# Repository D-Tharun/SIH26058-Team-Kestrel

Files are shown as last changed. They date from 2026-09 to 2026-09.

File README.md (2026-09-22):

# KESTREL — Adaptive Software-Defined Sonar Transmitter Payload for AUVs

**Smart India Hackathon 2026 — Problem Statement SIH26058**








| Team | Team ID | Institution |
|---|---|---|
| **KESTREL** | **127602** | SRM Institute of Science and Technology, Ramapuram |

> **Live Dashboard:** [aquachirp-sonar-transmitter.vercel.app](https://aquachirp-sonar-transmitter.vercel.app/)

---

## Hardware and Prototype Snapshot

**Measured on Rigol DS1054Z**

| Barker-13 | CW Signal | LFM Chirp |
| :---: | :---: | :---: |
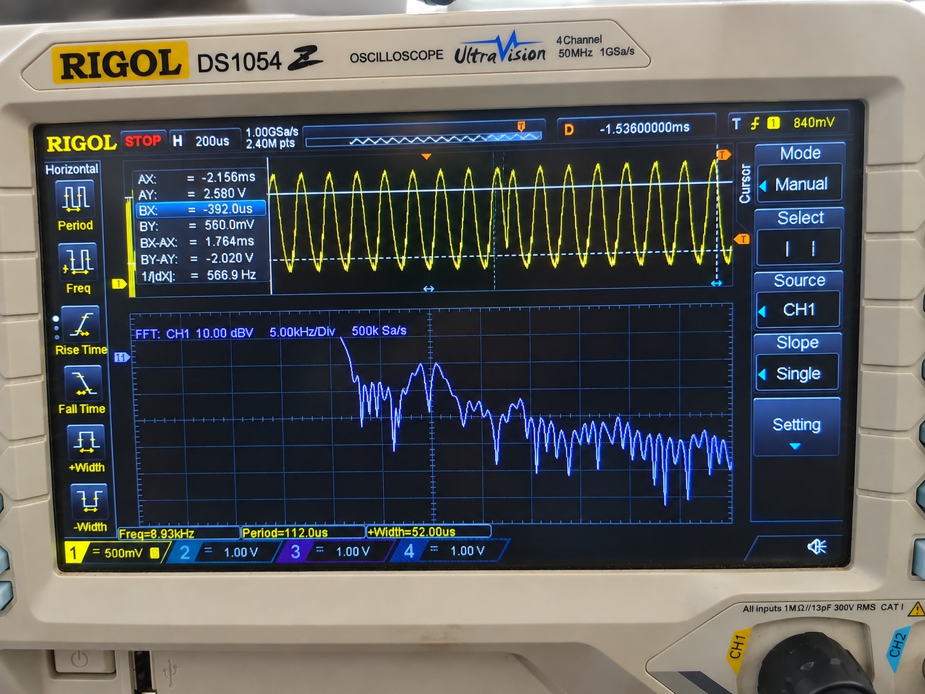
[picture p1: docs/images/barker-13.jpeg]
barker 13
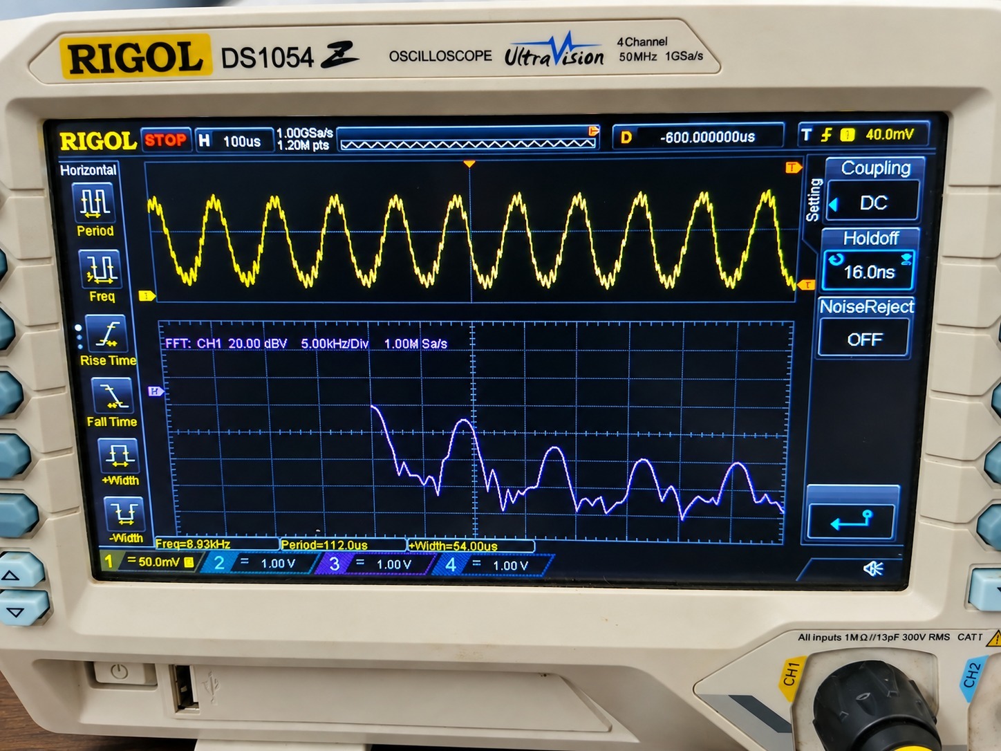
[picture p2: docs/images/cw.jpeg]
cw
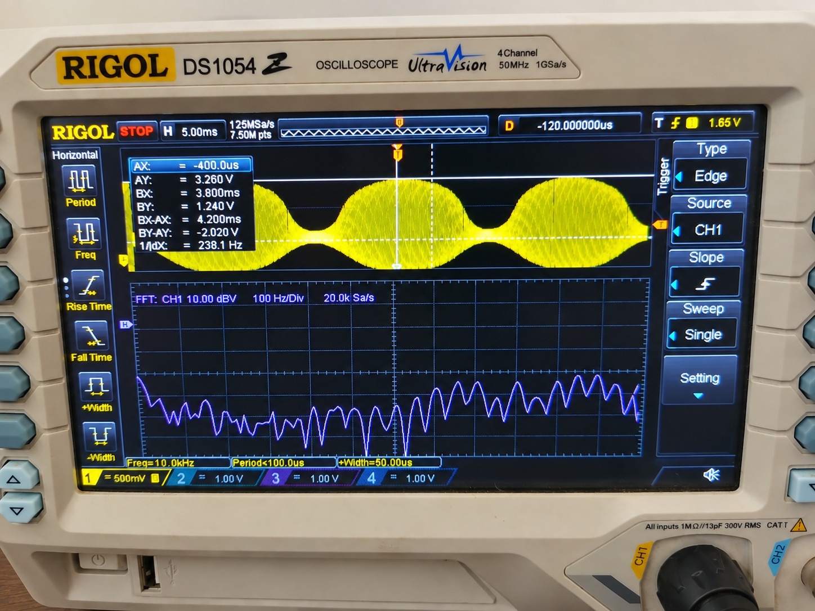
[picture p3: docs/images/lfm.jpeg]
lfm chirp
|  |  |  |

| Embedded Core | DAC | Physical Validation | Mechanical Integration |
|---|---|---|---|
| STM32F103RBT6 | MCP4921 12-bit | Rigol DS1054Z | AUV 3D CAD |

---

## Problem Statement

Conventional sonar transmitters are designed around fixed transmission parameters, making them inflexible when underwater environmental conditions change.

For an AUV operating in varying conditions, parameters such as depth, temperature, turbidity, salinity and the required balance between resolution and penetration can influence the choice of transmission strategy.

SIH26058 calls for a **software-defined, low-power and real-time adaptive sonar transmitter payload** capable of generating configurable waveforms and adapting its transmission parameters according to environmental conditions.

---

## Solution

KESTREL is a software-defined sonar transmitter payload built around an STM32 microcontroller and a configurable analog signal chain. The system continuously processes environmental inputs and selects an appropriate transmission strategy. The selected waveform is generated digitally, streamed through the DAC using hardware-timed data transfer, reconstructed through the analog signal chain, and validated using an oscilloscope.

**Core Pipeline: Sense — Adapt — Synthesize — Convert — Filter — Validate**

| PS Requirement | KESTREL Implementation |
|---|---|
| Software-defined transmitter | STM32-based firmware-controlled waveform generation |
| Real-time adaptation | Environmental inputs drive transmission-strategy selection |
| Multiple waveform types | CW, LFM Chirp, Geometric Sweep and Barker-13 phase coding |
| Low-power operation | Timer + DMA used for waveform sample streaming |
| Digital waveform synthesis | Firmware-generated waveform samples with LUT-based DDS |
| Analog transmission chain | MCP4921 DAC, CD4053B analog MUX, MCP6004 active filters |
| Real-time environmental inputs | Temperature, Turbidity, Salinity/TDS, Depth, Resolution-Penetration preference |
| Waveform validation | Rigol DS1054Z time-domain and FFT measurements |
| AUV payload integration | Compact 3D-designed streamlined payload enclosure |

---

## Repository Structure

```text
SIH26058-Team-Kestrel/
|
|-- firmware/                          STM32 Edge Firmware
|   +-- kestrel_waveform_engine.c      Adaptive DMA waveform engine (1556 lines)
|
|-- hardware/                          Physical Circuits and Interfaces
|   +-- Wiring Guide.md                Master pin-to-pin wiring reference
|
|-- mechanical/                        3D AUV Payload Concept
|   +-- cad/
|       |-- AUV_payload_streamlined.stl   230 mm x 100 mm hydrodynamic hull
|       |-- AUV_service_panel.stl         120 mm quick-access hatch
|       +-- AUV_hinge_pin.stl            3.4 mm diameter pivot dowel
|
|-- docs/                              Engineering Documentation
|   +-- Architecture.md                Complete system architecture flow
|
|-- src/                               Live Web DSP Telemetry Dashboard
|   |-- components/                     Oscilloscope, Waterfall, Radar, Decision views
|   |-- utils/                          Acoustic decision engine, signal generator
|   +-- App.tsx                         Main application with WebSerial integration
|
|-- README.md                          This file
|-- package.json                       Web dashboard dependencies
+-- vite.config.ts                     Build configuration
```

---

## System Architecture

```mermaid
graph TD
    subgraph Env["Environmental Inputs"]
        E1["Depth"]
        E2["Temperature"]
        E3["Turbidity"]
        E4["Salinity"]
        E5["Resolution / Penetration"]
    end
    
    subgraph MCU["STM32F103RBT6"]
        M1["Sensor Acquisition (ADC1/ADC2)"]
        M2["Adaptive Decision Engine"]
        M3["DDS Waveform Synthesis (LUT)"]
        M4["DMA Circular Buffer Streaming"]
    end

    Env --> MCU
    MCU -- "Timer + DMA" --> DAC["MCP4921 DAC<br>12-bit SPI"]
    MCU -- "Timer + DMA" --> TX["USART2 TX<br>115200 baud<br>JSON Telemetry"]
    
    DAC --> Analog["Analog Signal Chain<br>RC Filter<br>CD4053B MUX<br>MCP6004 Buffer"]
    TX --> Web["Web Dashboard<br>WebSerial API<br>React + Vite"]
    
    Analog --> Output["Analog Output"]
    Output --> DSO["Rigol DS1054Z<br>Time + FFT"]
```

---

## Signal Flow

```mermaid
flowchart TD
    A["Environmental Inputs"] --> B["STM32 ADC Data Acquisition"]
    B --> C["Adaptive Transmission Logic"]
    C --> D["Waveform Synthesis (Phase Accumulator + LUT)"]
    D --> E["Timer + DMA Sample Streaming"]
    E --> F["MCP4921 12-bit DAC"]
    F --> G["Analog Reconstruction Filter"]
    G --> H["CD4053B Filter Selection (PB5 controlled)"]
    H --> I["MCP6004 Buffer / Conditioning"]
    I --> J["Analog Output"]
    J --> K["Oscilloscope Validation (Time Domain + FFT)"]
```

---

## Adaptive Modulation Rules

The decision engine selects waveform modulation based on environmental state:

| Condition | Selected Modulation | Rationale |
|---|---|---|
| Depth > 80 m | Barker-13 (BPSK) | 11.1 dB pulse compression gain for deep-water clutter rejection |
| Turbidity < 30 NTU and Depth < 30 m | CW (Continuous Wave) | Narrowband Doppler estimation in clean shallow water |
| Turbidity > 60 NTU | LFM Chirp | Pulse compression through suspended particulate scattering |
| Turbidity 30-60 NTU | Geometric Sweep | Doppler-tolerant wideband energy for moderate scattering |
| Default fallback | Barker-13 | Standard phase coding for reliable SNR compression |

Window function selection follows SNR estimation:

| Condition | Window | Sidelobe Rejection |
|---|---|---|
| CW mode or SNR > 15 dB | Hamming | -43 dB |
| SNR 7-15 dB | Hann | -31 dB |
| SNR < 7 dB | Blackman | -58 dB |

---

## STM32 Pin Map

| Pin | Peripheral | Connection | Function |
|---|---|---|---|
| PA0 / A0 | ADC1_IN0 | Potentiometer 1 | Resolution / Penetration preference (0.0 - 1.0) |
| PA1 / A1 | ADC1_IN1 | Potentiometer 2 | Turbidity (SEN0189 / 10k-22k divider) |
| PA4 / A2 | ADC1_IN4 | Potentiometer 3 | Temperature (5 - 35 deg C) |
| PB0 / A3 | ADC1_IN8 | Potentiometer 4 | Depth / Water Level (0 - 200 m) |
| PC0 / A5 | ADC1_IN10 | Potentiometer 5 | Salinity / TDS (0 - 40 PSU) |
| PA6 / D12 | TIM3_CH1 | PWM Output | Waveform DMA output at 100 kSPS (ARR = 639) |
| PC1 / A4 | ADC2_IN11 | Self-Monitor | Final waveform loopback (64-sample feedback) |
| PB5 / D4 | GPIO Output | CD4053B Select | Dynamic filter capacitor selection |
| PA2 / D1 | USART2 TX | ST-LINK VCP | JSON telemetry at 115200 baud |
| PA3 / D0 | USART2 RX | ST-LINK VCP | Serial receive |
| PC13 | GPIO Output | User LED | DMA loop heartbeat indicator |

---

## Analog Signal Chain

```mermaid
flowchart TD
    PWM["PA6 / D12 (TIM3_CH1 PWM)"] --> R1["1kΩ Resistor"]
    R1 --> FILT1{"FILT1 Node"}
    
    FILT1 --> MUX["CD4053B MUX (Pin 14)"]
    MUX -- "PB5=0" --> C1["100 nF Capacitor to GND"]
    MUX -- "PB5=1" --> C2["10 nF Capacitor to GND"]
    
    FILT1 --> BUFA["MCP6004 Ch.A (Voltage Follower)"]
    BUFA --> R2["1kΩ Resistor"]
    R2 --> FILT2{"FILT2 Node"}
    
    FILT2 --> C3["10 nF Capacitor to GND"]
    FILT2 --> BUFB["MCP6004 Ch.B (Voltage Follower)"]
    
    BUFB --> WAVE{"FINAL WAVE Node"}
    WAVE --> DSO["DSO / Transducer"]
    WAVE --> R3["10kΩ Resistor"]
    
    R3 --> WAVEMON{"WAVE_MON Node"}
    WAVEMON --> ADC["PC1 / A4 (ADC2 Loopback)"]
    WAVEMON --> C4["1 nF Capacitor to GND"]
```

---

## Experimental Validation

### Oscilloscope Measurements

All waveforms were measured at the FINAL WAVE output node using a Rigol DS1054Z digital storage oscilloscope. (See the Hardware and Prototype Snapshot section at the top of this document for the waveform captures).

### Power Measurement

The transmitter signal chain was measured at 3.3 V using a digital multimeter connected in series with the supply.

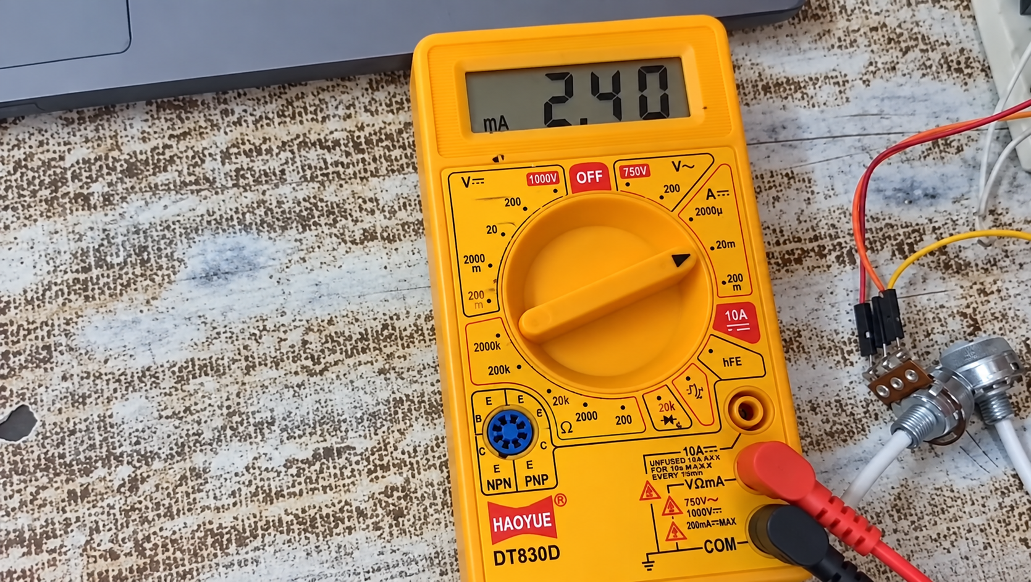
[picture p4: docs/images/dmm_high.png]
DMM Measurement

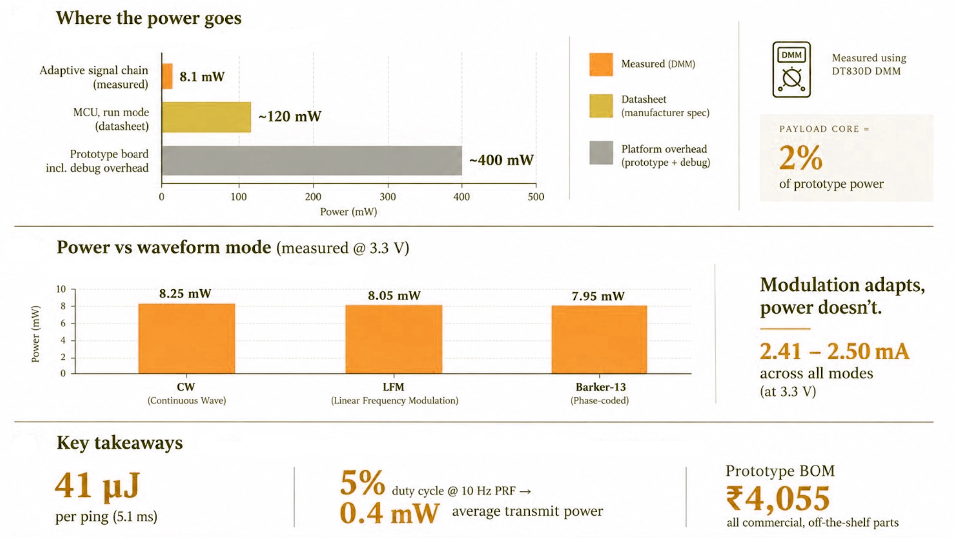
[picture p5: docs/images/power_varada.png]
Power Validation


| Waveform Mode | Measured Power | Equivalent Current |
|---|---:|---:|
| CW | 8.25 mW | 2.50 mA |
| LFM Chirp | 8.05 mW | 2.44 mA |
| Barker-13 | 7.95 mW | 2.41 mA |

Across all tested waveform modes, the measured signal-chain power remained within **7.95 - 8.25 mW**, corresponding to approximately **2.41 - 2.50 mA at 3.3 V**.

> **Measurement scope:** These values represent the 3.3 V transmitter signal-chain section only and do not represent the total power consumption of the complete development-board system.

---

## AUV Mechanical Integration

A 3D CAD enclosure was developed to explore the mechanical integration of the transmitter electronics into an AUV payload module.

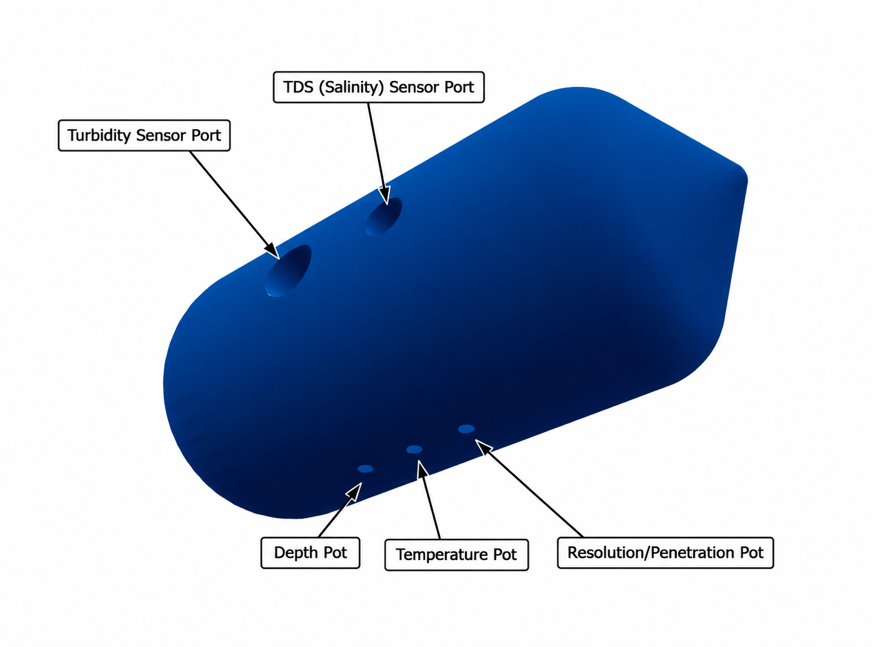
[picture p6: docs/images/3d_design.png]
3D CAD Concept


| Component | Dimensions | Description |
|---|---|---|
| Streamlined Hull | 230 mm x 100 mm diameter | Hydrodynamic cylindrical body of revolution |
| Service Panel | 120 mm x 80.6 mm arc | Quick-access hatch with conformal profile |
| Hinge Pin | 90.8 mm x 3.4 mm diameter | Cylindrical pivot dowel for panel articulation |

### Design Features

- Compact cylindrical form factor compatible with standard AUV payload bays
- Internal dry electronics cavity (62 - 92 mm inner diameter)
- Removable service panel with hinge mechanism for field access
- Rear cable pass-through provision
- Sensor and PCB mounting provisions
- Parabolic forebody profile for minimal hydrodynamic drag

> The current CAD represents a **prototype mechanical integration concept** and is not claimed as a pressure-rated or waterproof housing.

STL files are available in [`mechanical/cad/`](mechanical/cad/).

---

## Acoustic Physics

### Mackenzie Sound Speed Equation (1981)

```
c(T, S, D) = 1448.96 + 4.591T - 0.05304T^2 + 2.374e-4 T^3
            + 1.340(S - 35) + 1.630e-2 D + 1.675e-7 D^2
            - 1.025e-2 T(S - 35) - 7.139e-13 T D^3
```

Where T is temperature (deg C), S is salinity (PSU) and D is depth (m).

### Francois-Garrison Absorption Model

```
alpha(f) = A1*P1*(f1*f^2)/(f1^2 + f^2) + A2*P2*(f2*f^2)/(f2^2 + f^2) + A3*P3*f^2   [dB/km]
```

Accounts for Boric Acid relaxation, Magnesium Sulfate relaxation, and pure water viscous attenuation.

### Range Resolution and Pulse Compression

```
Delta_R = c / (2 * B)
G_p = 10 * log10(B * tau)   [dB]
```

---

## Serial Telemetry Protocol

The STM32 transmits line-delimited JSON frames at 10 Hz over USB Virtual COM Port (115200 baud):

```json
{
  "depth": 65.0,
  "turbidity": 0.42,
  "temperature": 21.0,
  "res_pen": 0.50,
  "salinity": 34.5,
  "sound_speed": 1522.4,
  "absorption": 1.20,
  "snr": 18.5,
  "center_freq": 2400.0,
  "bandwidth": 1522.4,
  "duration": 16.3,
  "amplitude": 0.61,
  "waveform_type": 1,
  "window_type": 0,
  "adc_samples": [320, 345, 390, 420, 380, 310, 260, 240, 280, 320]
}
```

---

## Getting Started

### Prerequisites

- [Node.js](https://nodejs.org/) v18 or higher
- Google Chrome, Microsoft Edge or any Chromium browser supporting the WebSerial API

### Clone the Repository

```bash
git clone https://github.com/D-Tharun/SIH26058-Team-Kestrel.git
cd SIH26058-Team-Kestrel
```

### Install Dependencies

```bash
npm install
```

### Start Development Server

```bash
npm run dev
```

Open [http://localhost:3000](http://localhost:3000) in your browser.

### Build for Production

```bash
npm run build
```

---

## Deployment

This repository is configured for zero-configuration deployment on Vercel:

1. Push this repository to GitHub.
2. Link the repository to [Vercel](https://vercel.com).
3. The platform will automatically build and deploy on every push.
4. Access the live HTTPS dashboard and click **Connect USB** to link your physical STM32 hardware.

**Live deployment:** [aquachirp-sonar-transmitter.vercel.app](https://aquachirp-sonar-transmitter.vercel.app/)

---

## Current Prototype Scope

### Demonstrated

- STM32 Nucleo F103RB embedded controller
- Controlled environmental-input emulation via potentiometers
- Adaptive waveform selection based on environmental state
- CW, LFM Chirp, Geometric Sweep and Barker-13 waveform generation
- MCP4921 DAC with Timer + DMA streaming
- Analog signal conditioning (MCP6004 + CD4053B + RC filtering)
- Physical DSO verification (time-domain and FFT)
- Signal-chain power measurement (7.95 - 8.25 mW)
- Mechanical CAD concept for AUV payload integration
- Real-time web telemetry dashboard with WebSerial API

### Future Development

- Real environmental sensors (DS18B20, SEN0189, TDS probe)
- Dedicated PCB layout
- Higher-frequency acoustic implementation
- Power amplifier stage
- Transducer integration and impedance matching
- Pressure-rated waterproof payload enclosure
- End-to-end underwater acoustic testing

---

## License

This project is open-source and available under the [MIT License](LICENSE).

---

**Team KESTREL | SIH26058 | SRM Institute of Science and Technology, Ramapuram**

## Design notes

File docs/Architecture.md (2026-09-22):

# KESTREL — SIH 26058
## Complete Project Architecture Flow

**Project:** Development of a Low-Power, Real-Time Adaptive Software-Defined Sonar Transmitter Payload for Autonomous Underwater Vehicles (AUVs)

---

## 1. Complete Architecture

```text
┌─────────────────────────────────────────────────────────────────────┐
│              CONTROLLED ENVIRONMENTAL INPUTS                       │
│                                                                     │
│  Depth │ Temperature │ Turbidity │ Salinity │ Resolution/Input     │
│                                                                     │
│  Current prototype: potentiometers used as input emulators         │
└───────────────────────────────┬─────────────────────────────────────┘
                                │
                                ▼
┌─────────────────────────────────────────────────────────────────────┐
│                     DATA ACQUISITION                                │
│                                                                     │
│                 STM32 Nucleo F103RB + ADC                           │
│                                                                     │
│       Analog input voltages → Digital environmental values          │
└───────────────────────────────┬─────────────────────────────────────┘
                                │
                                ▼
┌─────────────────────────────────────────────────────────────────────┐
│                 ENVIRONMENT ANALYSIS / ESTIMATION                  │
│                                                                     │
│  Interpret the current environmental state and determine the       │
│  required acoustic operating condition.                            │
└───────────────────────────────┬─────────────────────────────────────┘
                                │
                                ▼
┌─────────────────────────────────────────────────────────────────────┐
│                     ADAPTIVE DECISION                              │
│                                                                     │
│  Environmental state → waveform selection → parameter selection    │
│                                                                     │
│  Parameters:                                                        │
│  • Centre / carrier frequency                                       │
│  • Bandwidth                                                        │
│  • Pulse duration                                                   │
│  • Amplitude / signal level                                         │
│  • Modulation / coding                                              │
│  • Digital window                                                   │
│  • PRF / timing parameters                                          │
└───────────────────────────────┬─────────────────────────────────────┘
                                │
                 ┌──────────────┴──────────────┐
                 │                             │
                 ▼                             ▼
┌──────────────────────────┐       ┌──────────────────────────────────┐
│     PC DASHBOARD         │       │       WAVEFORM GENERATOR         │
│                          │       │                                  │
│ • Environmental values  │       │ • LUT / mathematical synthesis   │
│ • Selected waveform      │       │ • Phase accumulator               │
│ • Commanded parameters   │       │ • Waveform-specific generation   │
│ • Decision information   │       │ • Digital windowing              │
└──────────────────────────┘       └────────────────┬─────────────────┘
                                                    │
                                                    ▼
                                      ┌──────────────────────────────┐
                                      │       TIMER + DMA            │
                                      │                              │
                                      │ Timer → sample timing        │
                                      │ DMA   → sample transfer      │
                                      │                              │
                                      │ Reduces continuous CPU      │
                                      │ involvement during streaming │
                                      └───────────────┬──────────────┘
                                                      │
                                                      ▼
                                      ┌──────────────────────────────┐
                                      │        MCP4921 DAC           │
                                      │                              │
                                      │ Digital samples → analog     │
                                      │ voltage waveform              │
                                      └───────────────┬──────────────┘
                                                      │
                                                      ▼
                                      ┌──────────────────────────────┐
                                      │      ANALOG CONDITIONING     │
                                      │                              │
                                      │ • MCP6004 buffer/amplifier   │
                                      │ • Analog low-pass filter     │
                                      │ • Signal conditioning        │
                                      └───────────────┬──────────────┘
                                                      │
                                                      ▼
                                      ┌──────────────────────────────┐
                                      │       PHYSICAL OUTPUT        │
                                      │        WAVEFORM NODE         │
                                      └───────────────┬──────────────┘
                                                      │
                                                      ▼
                                      ┌──────────────────────────────┐
                                      │          VERIFY              │
                                      │                              │
                                      │ DSO time-domain measurement  │
                                      │ DSO FFT / spectrum analysis  │
                                      └───────────────┬──────────────┘
                                                      │
                                                      ▼
                                      ┌──────────────────────────────┐
                                      │     VALIDATION / FEEDBACK     │
                                      │                              │
                                      │ Compare commanded and        │
                                      │ measured waveform behaviour  │
                                      └───────────────┬──────────────┘
                                                      │
                                                      └──────► Next
                                                              input state
```

---

## 2. High-Level Architecture

```text
        ┌─────────┐
        │  SENSE  │
        └────┬────┘
             ↓
        ┌─────────┐
        │ ACQUIRE │
        └────┬────┘
             ↓
        ┌─────────┐
        │ ANALYSE │
        └────┬────┘
             ↓
        ┌─────────┐
        │  ADAPT  │
        └────┬────┘
             ↓
        ┌─────────┐
        │GENERATE │
        └────┬────┘
             ↓
        ┌─────────┐
        │   DAC   │
        └────┬────┘
             ↓
        ┌──────────────┐
        │   ANALOG     │
        │ CONDITIONING │
        └──────┬───────┘
               ↓
        ┌─────────┐
        │ VERIFY  │
        └────┬────┘
             ↓
          DSO + FFT
```

---

## 3. Environmental Input Layer

The current prototype uses five controlled potentiometer inputs as environmental-condition emulators.

```text
Depth
Temperature
Turbidity
Salinity
Resolution / related input
       │
       ▼
Analog voltage
       │
       ▼
STM32 ADC
       │
       ▼
Digital input values
```

These potentiometers should be described as **controlled environmental inputs/emulators**, not as functioning underwater sensors.

---

## 4. Embedded Controller

### STM32 Nucleo F103RB

The STM32 performs the central embedded processing:

1. Reads the ADC inputs.
2. Interprets the current environmental state.
3. Selects the adaptive waveform mode.
4. Determines waveform parameters.
5. Generates waveform samples.
6. Controls real-time sample streaming.
7. Interfaces with the external DAC.
8. Provides system information to the monitoring/dashboard layer.

---

## 5. Adaptive Decision Layer

The core project relationship is:

```text
Changing environmental inputs
             ↓
     Environment analysis
             ↓
       Adaptive decision
             ↓
    Waveform + parameters
```

The waveform modes demonstrated in the prototype are:

```text
                 ┌───────────┐
                 │    CW     │
                 └───────────┘

                 ┌───────────┐
                 │    LFM    │
                 └───────────┘

                 ┌───────────┐
                 │ Geometric │
                 │   Sweep   │
                 └───────────┘

                 ┌───────────┐
                 │ Barker-13 │
                 └───────────┘
```

---

## 6. Waveform Generation

The waveform engine uses mathematical synthesis on the STM32.

### General generation chain

```text
Waveform parameters
       ↓
Mathematical synthesis
       ↓
LUT / phase control
       ↓
Digital waveform samples
       ↓
Waveform buffer
```

### CW

```text
Constant phase increment
        ↓
Constant instantaneous frequency
        ↓
CW waveform
```

### LFM

```text
Changing phase increment
        ↓
Changing instantaneous frequency
        ↓
LFM chirp
```

### Geometric Sweep

```text
Time-varying frequency
according to implemented sweep relationship
        ↓
Geometric sweep waveform
```

### Barker-13

```text
Carrier
  +
Barker phase/sign sequence
  ↓
Phase-coded waveform
```

---

## 7. Digital Windowing

Where configured:

```text
Generated waveform
        ↓
Digital window
        ↓
Windowed waveform samples
        ↓
DAC streaming
```

The demonstrated configurations include windowing such as Hamming and Blackman.

---

## 8. Timer + DMA Architecture

The timer and DMA are important to the real-time hardware architecture.

```text
                WAVEFORM BUFFER
                       │
                       ▼
                     DMA
                       │
                       ▼
                  MCP4921 DAC
                       │
                       ▼
                Analog waveform

Hardware Timer
      │
      └── controls sample-update timing
```

### Hardware Timer

Controls when waveform samples are updated.

### DMA

Moves waveform samples toward the DAC without requiring the CPU to manually handle every individual sample transfer.

### CPU

Handles control logic, parameter processing and waveform preparation while hardware peripherals handle the repetitive streaming operation.

---

## 9. DAC and Analog Signal Chain

```text
STM32 waveform data
        ↓
      DMA
        ↓
   MCP4921 DAC
        ↓
   Analog voltage
        ↓
 MCP6004 / buffer
        ↓
 Analog low-pass filter
        ↓
 Conditioned analog waveform
        ↓
 Physical output node
```

---

## 10. Physical Verification

The output is physically verified using a Digital Storage Oscilloscope.

### Time-domain verification

```text
Physical analog output
        ↓
        DSO
        ↓
• Waveform shape
• Period
• Local frequency
• Pulse behaviour
```

### Frequency-domain verification

```text
Physical analog output
        ↓
      DSO FFT
        ↓
• Dominant frequency
• Spectrum
• Frequency-domain behaviour
```

The terminology should distinguish between:

- **Commanded value** — requested by the controller.
- **Measured value** — observed on the DSO.

---

## 11. PC Dashboard

The dashboard is a monitoring/presentation layer.

```text
                 STM32
                   │
          ┌────────┴────────┐
          │                 │
          ▼                 ▼
   PC Dashboard       Waveform Engine
          │                 │
          │                 ▼
          │              DMA/DAC
          │                 │
          ▼                 ▼
 Selected waveform      Physical output
 Parameters                  │
 Decision state               ▼
                          DSO / FFT
```

The dashboard displays system state and commanded parameters; the physical analog waveform is generated by the embedded hardware and DAC/analog chain.

---

## 12. Complete Signal Path

```text
Environmental inputs
        ↓
STM32 ADC
        ↓
Environment analysis
        ↓
Adaptive decision
        ↓
Waveform selection
        ↓
Parameter generation
        ↓
Waveform synthesis
        ↓
Digital windowing
        ↓
Waveform buffer
        ↓
Hardware Timer + DMA
        ↓
MCP4921 DAC
        ↓
MCP6004 / analog conditioning
        ↓
Analog low-pass filter
        ↓
Physical waveform output
        ↓
DSO
   ┌────┴────┐
   ↓         ↓
Time       FFT
domain     spectrum
```

---

## 13. Closed Adaptive Loop

```text
        ┌───────────────────────────┐
        │ ENVIRONMENTAL INPUT       │
        │ Controlled / emulated     │
        └─────────────┬─────────────┘
                      ↓
        ┌───────────────────────────┐
        │ ACQUIRE                    │
        │ STM32 ADC                  │
        └─────────────┬─────────────┘
                      ↓
        ┌───────────────────────────┐
        │ ANALYSE                    │
        │ Environmental state        │
        └─────────────┬─────────────┘
                      ↓
        ┌───────────────────────────┐
        │ ADAPT                      │
        │ Waveform + parameters      │
        └─────────────┬─────────────┘
                      ↓
        ┌───────────────────────────┐
        │ GENERATE                   │
        │ Mathematical synthesis     │
        └─────────────┬─────────────┘
                      ↓
        ┌───────────────────────────┐
        │ DAC + ANALOG CONDITIONING │
        └─────────────┬─────────────┘
                      ↓
        ┌───────────────────────────┐
        │ PHYSICAL OUTPUT            │
        └─────────────┬─────────────┘
                      ↓
        ┌───────────────────────────┐
        │ VERIFY                     │
        │ DSO + FFT                  │
        └─────────────┬─────────────┘
                      │
                      └──────────────► Next environmental state
```

---

## 14. Power Architecture

The demonstrated power measurement applies to the **signal-generation electronics**.

```text
3.3 V supply
    ↓
Signal-generation electronics
    ↓
Measured current ≈ 2.4 mA
    ↓
Power ≈ 8 mW
```

This measurement does **not** represent:

- Total AUV payload power.
- Acoustic transmit power.
- Power consumption of a completed power amplifier.
- Transducer power.

The current prototype does not include the final power-amplifier and transducer stage.

---

## 15. Mechanical Payload Concept

The CAD concept provides a possible mechanical package for the electronics.

```text
        Streamlined cylindrical payload
                    │
        ┌───────────┴───────────┐
        │                       │
        ▼                       ▼
 Sensor openings        Side access ports
        │                       │
        │                Potentiometer access
        │
        └───────────┬───────────┘
                    ↓
             Electronics/
             service region
```

The current CAD is a concept design and is not a final pressure-rated or waterproof housing.

---

## 16. Current Prototype Scope

### Demonstrated

- STM32 Nucleo F103RB
- Controlled environmental-input emulation
- Adaptive waveform selection
- CW
- LFM
- Geometric sweep
- Barker-13 implementation
- MCP4921 DAC
- Timer/DMA streaming architecture
- Analog conditioning
- Physical DSO verification
- FFT/spectrum observation
- Signal-generation power measurement
- Mechanical CAD concept

### Future Development

- Real environmental sensors
- Dedicated PCB
- Higher-frequency implementation
- Power amplifier
- Transducer integration
- Final waterproof / pressure-rated payload enclosure
- End-to-end underwater acoustic testing

---

## 17. Final One-Line Architecture

> **ENVIRONMENT INPUT → ADC → ANALYSE → ADAPT → WAVEFORM GENERATION → TIMER + DMA → MCP4921 DAC → ANALOG CONDITIONING → PHYSICAL OUTPUT → DSO / FFT VERIFY**

---

## 18. Five-Word Project Story

> **SENSE → ANALYSE → ADAPT → GENERATE → VERIFY**

This is the simplest high-level representation of the KESTREL adaptive sonar transmitter architecture.

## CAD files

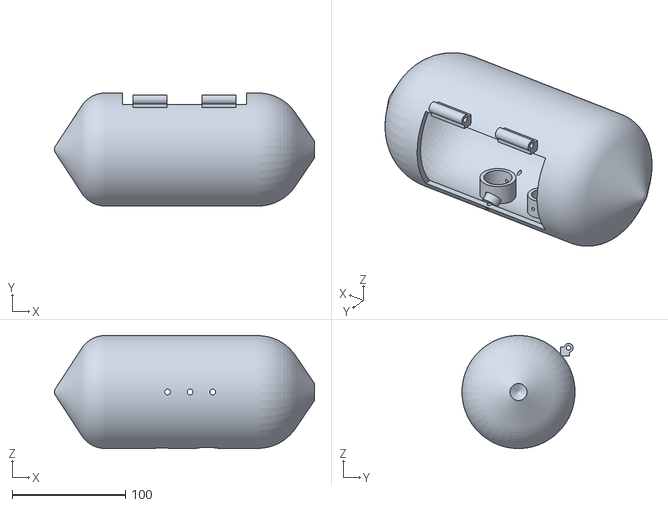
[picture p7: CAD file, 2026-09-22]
mechanical/cad/AUV_payload_streamlined.stl
230.0 x 100.0 x 100.0

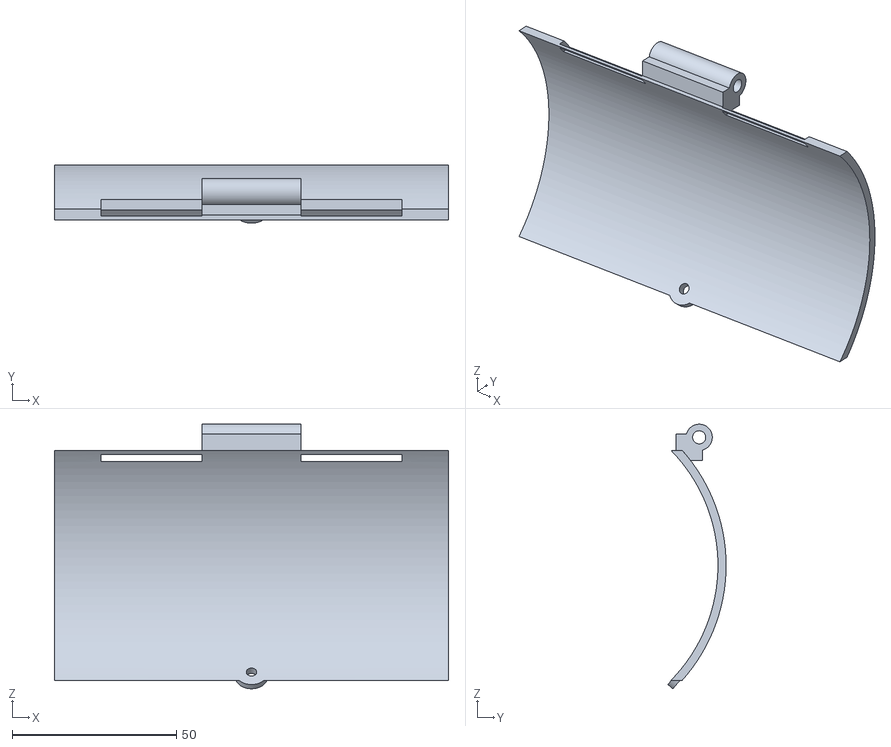
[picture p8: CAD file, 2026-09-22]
mechanical/cad/AUV_service_panel.stl
120.0 x 17.8 x 80.6

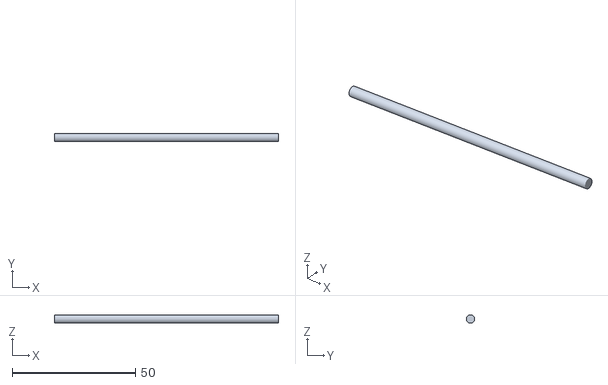
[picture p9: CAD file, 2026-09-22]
mechanical/cad/AUV_hinge_pin.stl
90.8 x 3.40 x 3.40

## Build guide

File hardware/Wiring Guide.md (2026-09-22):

## SIH 26058 — Adaptive Software-Defined Sonar Transmitter Payload

This guide documents the **5-pot prototype input configuration** used for environmental-input emulation.

The five 10 kΩ potentiometers represent:

1. Resolution / Penetration preference
2. Turbidity
3. Temperature
4. Depth
5. Salinity

All five potentiometers are wired as voltage dividers between **3.3 V and GND**. The **wiper** of each potentiometer goes to one STM32 ADC input.

---

## 1. Five-Pot Wiring Summary

| Potentiometer | Parameter | Value | One outer pin | Wiper | Other outer pin |
|---|---|---:|---|---|---|
| POT1 | RES-PEN | 10 kΩ | 3.3 V | PA0 / A0 | GND |
| POT2 | TURBIDITY | 10 kΩ | 3.3 V | PA1 / A1 | GND |
| POT3 | TEMP | 10 kΩ | 3.3 V | PA4 / A2 | GND |
| POT4 | DEPTH | 10 kΩ | 3.3 V | PB0 / A3 | GND |
| POT5 | SALINITY | 10 kΩ | 3.3 V | PC0 / A5 | GND |

> **Important:** The two outer terminals of every potentiometer form the 3.3 V–GND voltage divider. The center terminal is the ADC wiper.

---

## 2. Standard Potentiometer Connection

Each 10 kΩ potentiometer is wired in the same basic way:

```text
                 3.3 V
                   |
             +-----+-----+
             |   10 kΩ  |
             |    POT   |
             +-----+-----+
                   |
                  GND

                 WIPER
                   |
                   +-------- STM32 ADC INPUT
```

The wiper voltage varies approximately from **0 V to 3.3 V** as the knob is rotated.

---

## 3. POT1 — Resolution / Penetration

**Purpose:** Emulates the resolution-versus-penetration preference.

```text
POT1 — 10 kΩ

Outer pin 1  -> 3.3 V
Wiper        -> PA0 / A0
Outer pin 2  -> GND
```

**Label:** `RES-PEN`

---

## 4. POT2 — Turbidity

**Purpose:** Emulates the water turbidity/environmental condition.

```text
POT2 — 10 kΩ

Outer pin 1  -> 3.3 V
Wiper        -> PA1 / A1
Outer pin 2  -> GND
```

**Label:** `TURBIDITY`

---

## 5. POT3 — Temperature

**Purpose:** Emulates the temperature input during 5-pot prototype mode.

```text
POT3 — 10 kΩ

Outer pin 1  -> 3.3 V
Wiper        -> PA4 / A2
Outer pin 2  -> GND
```

**Label:** `TEMP`

---

## 6. POT4 — Depth

**Purpose:** Emulates operating depth.

```text
POT4 — 10 kΩ

Outer pin 1  -> 3.3 V
Wiper        -> PB0 / A3
Outer pin 2  -> GND
```

**Label:** `DEPTH`

---

## 7. POT5 — Salinity

**Purpose:** Emulates salinity/TDS during prototype mode.

```text
POT5 — 10 kΩ

Outer pin 1  -> 3.3 V
Wiper        -> PC0 / A5
Outer pin 2  -> GND
```

**Label:** `SALINITY`

---

## 8. Complete Five-Pot Wiring

```text
                         STM32 NUCLEO
                    +------------------+
                    |                  |
3.3 V --------------+------------------+-------------------+
                    |                  |                   |
GND ----------------+------------------+---------------+   |
                    |                  |               |   |
PA0 / A0 -----------+------------------+-----------+   |   |
PA1 / A1 -----------+------------------+---------+ |   |   |
PA4 / A2 -----------+------------------+-------+ | |   |   |
PB0 / A3 -----------+------------------+-----+ | | |   |   |
PC0 / A5 -----------+------------------+---+ | | | |   |   |
                    +------------------+   | | | | |   |   |
                                           | | | | |   |   |
             POT1 RES-PEN                  | | | | |   |   |
        3.3 V ----+                        | | | | |   |   |
                  | 10 kΩ                   | | | | |   |   |
                  +--- WIPER --------------+ | | | |   |   |
                  |      -> PA0 / A0         | | | |   |   |
        GND ------+                          | | | |   |   |
                                             | | | |   |   |
             POT2 TURBIDITY                  | | | |   |   |
        3.3 V ----+                          | | | |   |   |
                  | 10 kΩ                    | | | |   |   |
                  +--- WIPER ----------------+ | | |   |   |
                  |      -> PA1 / A1          | | |   |   |
        GND ------+                            | | |   |   |
                                               | | |   |   |
             POT3 TEMP                         | | |   |   |
        3.3 V ----+                            | | |   |   |
                  | 10 kΩ                      | | |   |   |
                  +--- WIPER ------------------+ | |   |   |
                  |      -> PA4 / A2            | | |   |   |
        GND ------+                              | |   |   |
                                                 | |   |   |
             POT4 DEPTH                          | |   |   |
        3.3 V ----+                              | |   |   |
                  | 10 kΩ                        | |   |   |
                  +--- WIPER --------------------+ |   |   |
                  |      -> PB0 / A3              | |   |   |
        GND ------+                                |   |   |
                                                   |   |   |
             POT5 SALINITY                         |   |   |
        3.3 V ----+                                |   |   |
                  | 10 kΩ                          |   |   |
                  +--- WIPER ----------------------+   |   |
                  |      -> PC0 / A5                   |   |
        GND ------+                                    |
```

For the physical prototype, use common **3.3 V** and **GND** rails and route each wiper separately to its assigned ADC pin.

---

## 9. STM32 ADC Mapping

| Parameter | STM32 Pin | Prototype Input |
|---|---|---|
| Resolution / Penetration | PA0 / A0 | POT1 |
| Turbidity | PA1 / A1 | POT2 |
| Temperature | PA4 / A2 | POT3 |
| Depth | PB0 / A3 | POT4 |
| Salinity | PC0 / A5 | POT5 |

Other relevant STM32 connections:

| STM32 pin | Function |
|---|---|
| PA6 | Current prototype waveform input / PWM path |
| PB5 | CD4053 A control |
| PC1 | FINAL WAVE self-monitor |
| 3V3 | Potentiometer supply |
| GND | Common ground |

**No 5 V rail is used for the five-pot prototype inputs.**

---

## 10. Electrical Principle

```text
POT POSITION
     |
     v
ANALOG VOLTAGE (0–3.3 V)
     |
     v
STM32 ADC
     |
     v
DIGITAL VALUE
     |
     v
ENVIRONMENTAL PARAMETER
     |
     v
ADAPTIVE TRANSMITTER DECISION
```

Each potentiometer acts as a variable voltage divider:

```text
3.3 V
  |
 10 kΩ POT
  |
 WIPER ---------> STM32 ADC
  |
 GND
```

---

## 11. MCP4921 DAC Wiring

The MCP4921 is the external 12-bit DAC used in the DAC-based waveform-generation path.

```text
STM32 NUCLEO              MCP4921 DAC
+-----------+             +-----------+
| PA5       | ----------> | SCK       |
| PA7       | ----------> | SDI/MOSI  |
| PB6       | ----------> | CS        |
| 3.3 V     | ----------> | VDD       |
| GND       | ----------> | VSS       |
+-----------+             |           |
                          | VOUT -----> R1 (1 kΩ)
                          +-----------+
                                      |
                                      v
                                    FILT1
                                      |
                                      v
                                    CD4053B
```

### MCP4921 Pin Connections

| MCP4921 pin/function | Connection |
|---|---|
| VDD | 3.3 V |
| VSS | GND |
| SCK | STM32 PA5 / SPI clock |
| SDI | STM32 PA7 / SPI MOSI |
| CS | STM32 PB6 / chip select |
| VOUT | R1 (1 kΩ) → FILT1 → CD4053B signal path |

Use a common ground between the STM32 and MCP4921.

The DAC signal path is:

```text
STM32 SPI
   |
   v
MCP4921 (12-bit DAC)
   |
   v
VOUT
   |
   v
R1 = 1 kΩ
   |
   v
FILT1
   |
   v
CD4053B
   |
   v
MCP6004 buffer
   |
   v
FINAL WAVE
```

This is the external-DAC waveform-generation configuration and is separate from the five-pot environmental-input wiring.

---
---

## 12. Final Five-Pot Pin Map

```text
POT1 RES-PEN    : 3.3 V -> 10 kΩ POT -> WIPER -> PA0/A0 -> GND
POT2 TURBIDITY  : 3.3 V -> 10 kΩ POT -> WIPER -> PA1/A1 -> GND
POT3 TEMP       : 3.3 V -> 10 kΩ POT -> WIPER -> PA4/A2 -> GND
POT4 DEPTH      : 3.3 V -> 10 kΩ POT -> WIPER -> PB0/A3 -> GND
POT5 SALINITY   : 3.3 V -> 10 kΩ POT -> WIPER -> PC0/A5 -> GND
```

**This is the complete 5-pot environmental-emulation wiring configuration for the AquaChirp prototype.**

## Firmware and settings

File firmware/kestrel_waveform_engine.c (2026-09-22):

#include "main.h"
#include <stdio.h>
#include <string.h>
#include <math.h>
#include <stdint.h>

#ifndef M_PI
#define M_PI 3.14159265358979323846
#endif

#define PWM_MAX                 639U
#define PWM_MID                 320U
#define PWM_SWING_MAX           280U

#define SAMPLE_RATE_HZ          100000U
#define WAVE_BUF_SIZE           512U
#define WAVE_HALF               256U

#define SINE_LUT_SIZE           1024U
#define WINDOW_LUT_SIZE         256U

#define MIN_FREQ_HZ             500.0f
#define MAX_FREQ_HZ             9000.0f

#define SENSOR_PERIOD_MS        100U
#define TELEMETRY_PERIOD_MS     100U

#define TELEMETRY_ADC_SAMPLES   64U

#define PHASE_TWO_PI            4294967296.0

typedef struct
{
    uint32_t inc_start;
    uint32_t inc_end;
    uint32_t pulse_samples;
    uint16_t swing;
    uint8_t mod_type;
    uint8_t window_type;
} wave_cfg_t;

UART_HandleTypeDef huart2;
ADC_HandleTypeDef hadc1;
ADC_HandleTypeDef hadc2;
TIM_HandleTypeDef htim3;
DMA_HandleTypeDef hdma_tim3_ch1_trig;

static volatile uint16_t wave_buf[WAVE_BUF_SIZE];

static int16_t sine_lut[SINE_LUT_SIZE];
static uint16_t window_lut[3][WINDOW_LUT_SIZE];

static volatile uint32_t phase_acc_q32 = 0U;
static volatile uint32_t pulse_sample = 0U;

static volatile wave_cfg_t active_cfg;
static wave_cfg_t pending_cfg;
static volatile uint8_t config_pending = 0U;

typedef struct
{
    float depth;
    float turbidity;
    float temperature;
    float res_pen;
    float salinity;

    float sound_speed;
    float absorption;
    float snr;
    float center_freq;
    float bandwidth;
    float duration;
    float amplitude;

    int mod_type;
    int window_type;

    float probe_freqs[3];
    float probe_snr[3];
    int probe_winner;
    int probe_active;
} env_params_t;

static env_params_t env;

static volatile uint16_t pot_adc[5] = {0};

static uint16_t mon_samples[TELEMETRY_ADC_SAMPLES];
static uint16_t mon_min = 4095U;
static uint16_t mon_max = 0U;
static uint32_t mon_sum = 0U;

static char uart_buf[4096];

void SystemClock_Config(void);

static void MX_GPIO_Init(void);
static void MX_USART2_UART_Init(void);
static void MX_ADC1_Init(void);
static void MX_ADC2_Init(void);
static void MX_TIM3_Init(void);
static void MX_DMA_Init(void);

static float clampf_local(float x, float lo, float hi);

static void init_luts(void);
static uint32_t hz_to_phase_inc(float hz);
static uint16_t window_q15(uint8_t type, uint32_t n);

static uint16_t read_adc_channel(uint32_t channel);
static void read_pots(void);
static void compute_environment(void);

static void set_mux_filter(int heavy);

static void commit_wave_config(void);
static void apply_pending_config_if_ready(void);

static void generate_wave_half(uint16_t *buf, uint16_t count);
static void initialize_wave_buffer(void);

static void read_self_monitor(void);
static void send_dashboard(void);

static float clampf_local(float x, float lo, float hi)
{
    if (x < lo) return lo;
    if (x > hi) return hi;
    return x;
}

static uint32_t hz_to_phase_inc(float hz)
{
    double inc =
        ((double)hz * PHASE_TWO_PI) /
        (double)SAMPLE_RATE_HZ;

    if (inc <= 0.0)
        return 0U;

    if (inc >= 4294967295.0)
        return 0xFFFFFFFFU;

    return (uint32_t)(inc + 0.5);
}

static void init_luts(void)
{
    for (uint32_t i = 0U; i < SINE_LUT_SIZE; ++i) {
        float a =
            (2.0f * (float)M_PI * (float)i) /
            (float)SINE_LUT_SIZE;

        sine_lut[i] =
            (int16_t)lroundf(
                sinf(a) * 32767.0f);
    }

    for (uint32_t i = 0U; i < WINDOW_LUT_SIZE; ++i) {
        float n =
            (float)i /
            (float)(WINDOW_LUT_SIZE - 1U);

        float hamming =
            0.54f -
            0.46f *
            cosf(2.0f * (float)M_PI * n);

        float hann =
            0.50f -
            0.50f *
            cosf(2.0f * (float)M_PI * n);

        float blackman =
            0.42f -
            0.50f *
            cosf(2.0f * (float)M_PI * n) +
            0.08f *
            cosf(4.0f * (float)M_PI * n);

        hamming = clampf_local(hamming, 0.0f, 1.0f);
        hann = clampf_local(hann, 0.0f, 1.0f);
        blackman = clampf_local(blackman, 0.0f, 1.0f);

        window_lut[0][i] =
            (uint16_t)lroundf(hamming * 32767.0f);

        window_lut[1][i] =
            (uint16_t)lroundf(hann * 32767.0f);

        window_lut[2][i] =
            (uint16_t)lroundf(blackman * 32767.0f);
    }
}

static uint16_t read_adc_channel(uint32_t channel)
{
    ADC_ChannelConfTypeDef cfg = {0};

    cfg.Channel = channel;
    cfg.Rank = 1;
    cfg.SamplingTime = ADC_SAMPLETIME_55CYCLES_5;

    if (HAL_ADC_ConfigChannel(&hadc1, &cfg) != HAL_OK)
        return 0U;

    if (HAL_ADC_Start(&hadc1) != HAL_OK)
        return 0U;

    if (HAL_ADC_PollForConversion(&hadc1, 10U) != HAL_OK) {
        HAL_ADC_Stop(&hadc1);
        return 0U;
    }

    uint16_t val =
        (uint16_t)HAL_ADC_GetValue(&hadc1);

    HAL_ADC_Stop(&hadc1);

    return val;
}

static void read_pots(void)
{

    pot_adc[0] =
        read_adc_channel(ADC_CHANNEL_0);   

    pot_adc[1] =
        read_adc_channel(ADC_CHANNEL_1);   

    pot_adc[2] =
        read_adc_channel(ADC_CHANNEL_4);   

    pot_adc[3] =
        read_adc_channel(ADC_CHANNEL_8);   

    pot_adc[4] =
        read_adc_channel(ADC_CHANNEL_10);  

    env.depth =
        ((float)pot_adc[3] / 4095.0f) * 200.0f;

    env.turbidity =
        1.0f -
        ((float)pot_adc[1] / 4095.0f);

    env.temperature =
        5.0f +
        ((float)pot_adc[2] / 4095.0f) * 30.0f;

    env.res_pen =
        (float)pot_adc[0] / 4095.0f;

    env.salinity =
        ((float)pot_adc[4] / 4095.0f) * 40.0f;
}

static void compute_environment(void)
{
    float T = env.temperature;
    float S = env.salinity;
    float D = env.depth;

    env.sound_speed =
          1448.96f
        + 4.591f * T
        - 0.05304f * T * T
        + 1.340f * (S - 35.0f)
        + 0.0163f * D
        + 1.675e-7f * D * D
        - 7.139e-13f * D * D * D;

    float two_way_km =
        (2.0f * D) / 1000.0f;

    float best_freq = 500.0f;
    const float max_loss_db = 25.0f;

    for (float f = 500.0f;
         f <= 10000.0f;
         f += 100.0f) {

        float f_kHz = f / 1000.0f;

        float alpha_boric =
            0.11f *
            (f_kHz * f_kHz) /
            (1.0f + f_kHz * f_kHz);

        float alpha_magnesia =
            0.002f *
            (f_kHz * f_kHz) /
            (4.0f + f_kHz * f_kHz);

        float alpha_water =
            0.00003f *
            f_kHz * f_kHz;

        float alpha_turbidity =
            env.turbidity *
            0.05f *
            f_kHz;

        float alpha_total =
            alpha_boric +
            alpha_magnesia +
            alpha_water +
            alpha_turbidity;

        float round_trip_loss =
            alpha_total *
            two_way_km;

        if (round_trip_loss < max_loss_db)
            best_freq = f;
    }

    {
        float f_kHz =
            best_freq / 1000.0f;

        float alpha_boric =
            0.11f *
            (f_kHz * f_kHz) /
            (1.0f + f_kHz * f_kHz);

        float alpha_magnesia =
            0.002f *
            (f_kHz * f_kHz) /
            (4.0f + f_kHz * f_kHz);

        float alpha_water =
            0.00003f *
            f_kHz * f_kHz;

        float alpha_turbidity =
            env.turbidity *
            0.05f *
            f_kHz;

        env.absorption =
            alpha_boric +
            alpha_magnesia +
            alpha_water +
            alpha_turbidity;
    }

    float penetration_freq =
        best_freq * 0.4f;

    env.center_freq =
        penetration_freq +
        (best_freq - penetration_freq) *
        env.res_pen;

    env.center_freq =
        clampf_local(
            env.center_freq,
            MIN_FREQ_HZ,
            MAX_FREQ_HZ);

    float range_factor =
        1.0f -
        (D / 250.0f);

    if (range_factor < 0.1f)
        range_factor = 0.1f;

    float turb_factor =
        1.0f -
        env.turbidity;

    env.snr =
        20.0f * range_factor +
        10.0f * turb_factor;

    if (env.snr < 0.0f)
        env.snr = 0.0f;

    const float desired_resolution = 0.5f;

    env.bandwidth =
        env.sound_speed /
        (2.0f * desired_resolution);

    env.bandwidth =
        clampf_local(
            env.bandwidth,
            500.0f,
            7000.0f);

    env.duration =
        5.0f +
        (D / 200.0f) * 35.0f;

    env.duration =
        clampf_local(
            env.duration,
            2.56f,
            20.0f);

    env.amplitude =
        0.4f +
        (D / 200.0f) * 0.4f +
        env.turbidity * 0.2f;

    env.amplitude =
        clampf_local(
            env.amplitude,
            0.25f,
            0.95f);

    if (env.turbidity < 0.3f &&
        D < 30.0f) {

        env.mod_type = 0; 

    } else if (env.turbidity > 0.6f) {

        env.mod_type = 1; 

    } else if (env.turbidity >= 0.3f &&
               env.turbidity <= 0.6f) {

        env.mod_type = 2; 

    } else {

        env.mod_type = 3; 
    }

    if (D > 80.0f)
        env.mod_type = 3;

    if (env.mod_type == 0) {
        env.window_type = 0; 
    } else if (env.snr > 15.0f) {
        env.window_type = 0;
    } else if (env.snr > 7.0f) {
        env.window_type = 1; 
    } else {
        env.window_type = 2; 
    }

    if (env.center_freq < 2000.0f)
        set_mux_filter(1);
    else
        set_mux_filter(0);

    env.probe_active = 0;
    env.probe_winner = 1;

    env.probe_freqs[0] =
        env.center_freq * 0.9f;

    env.probe_freqs[1] =
        env.center_freq;

    env.probe_freqs[2] =
        env.center_freq * 1.1f;

    env.probe_snr[0] = 0.0f;
    env.probe_snr[1] = 0.0f;
    env.probe_snr[2] = 0.0f;

    commit_wave_config();
}

static void set_mux_filter(int heavy)
{

    if (heavy) {
        HAL_GPIO_WritePin(
            GPIOB,
            GPIO_PIN_5,
            GPIO_PIN_RESET);
    } else {
        HAL_GPIO_WritePin(
            GPIOB,
            GPIO_PIN_5,
            GPIO_PIN_SET);
    }
}

static void commit_wave_config(void)
{
    float fc =
        clampf_local(
            env.center_freq,
            MIN_FREQ_HZ,
            MAX_FREQ_HZ);

    float bw =
        clampf_local(
            env.bandwidth,
            500.0f,
            7000.0f);

    float f0 =
        fc -
        0.5f * bw;

    float f1 =
        fc +
        0.5f * bw;

    f0 =
        clampf_local(
            f0,
            MIN_FREQ_HZ,
            MAX_FREQ_HZ);

    f1 =
        clampf_local(
            f1,
            MIN_FREQ_HZ,
            MAX_FREQ_HZ);

    if (env.mod_type == 0 ||
        env.mod_type == 3) {

        f0 = fc;
        f1 = fc;
    }

    uint32_t pulse_samples =
        (uint32_t)lroundf(
            env.duration *
            0.001f *
            (float)SAMPLE_RATE_HZ);

    if (pulse_samples < 256U)
        pulse_samples = 256U;

    if (pulse_samples > 2000U)
        pulse_samples = 2000U;

    pending_cfg.inc_start =
        hz_to_phase_inc(f0);

    pending_cfg.inc_end =
        hz_to_phase_inc(f1);

    pending_cfg.pulse_samples =
        pulse_samples;

    pending_cfg.swing =
        (uint16_t)lroundf(
            PWM_SWING_MAX *
            env.amplitude);

    if (pending_cfg.swing < 1U)
        pending_cfg.swing = 1U;

    if (pending_cfg.swing > PWM_SWING_MAX)
        pending_cfg.swing = PWM_SWING_MAX;

    pending_cfg.mod_type =
        (uint8_t)env.mod_type;

    pending_cfg.window_type =
        (uint8_t)env.window_type;

    __disable_irq();
    config_pending = 1U;
    __enable_irq();
}

static void apply_pending_config_if_ready(void)
{
    if (!config_pending)
        return;

    active_cfg =
        pending_cfg;

    pulse_sample = 0U;

    __disable_irq();
    config_pending = 0U;
    __enable_irq();
}

static void generate_wave_half(uint16_t *buf,
                               uint16_t count)
{
    const uint32_t inc0 =
        active_cfg.inc_start;

    const uint32_t inc1 =
        active_cfg.inc_end;

    const uint32_t total =
        (active_cfg.pulse_samples > 1U)
        ? active_cfg.pulse_samples
        : 2U;

    const uint16_t swing =
        active_cfg.swing;

    const uint8_t mode =
        active_cfg.mod_type;

    const uint8_t win =
        active_cfg.window_type;

    uint32_t p =
        pulse_sample;

    for (uint16_t i = 0U;
         i < count;
         ++i) {

        uint32_t pos =
            (p < total) ? p : 0U;

        uint32_t n256 =
            (uint32_t)(
                ((uint64_t)pos * 255ULL) /
                (uint64_t)(total - 1U));

        if (n256 > 255U)
            n256 = 255U;

        uint32_t inc =
            inc0;

        if (mode == 1U) { 

            int64_t d =
                (int64_t)(uint64_t)inc1 -
                (int64_t)(uint64_t)inc0;

            inc =
                (uint32_t)(
                    (int64_t)inc0 +
                    (d * (int64_t)pos) /
                    (int64_t)(total - 1U));
        }
        else if (mode == 2U) { 

            uint64_t nn =
                (uint64_t)pos *
                (uint64_t)pos;

            uint64_t dd =
                (uint64_t)(total - 1U) *
                (uint64_t)(total - 1U);

            int64_t d =
                (int64_t)(uint64_t)inc1 -
                (int64_t)(uint64_t)inc0;

            if (dd != 0U) {
                inc =
                    (uint32_t)(
                        (int64_t)inc0 +
                        (((int64_t)d *
                          (int64_t)nn) /
                         (int64_t)dd));
            }
        }

        phase_acc_q32 += inc;

        uint16_t idx =
            (uint16_t)(
                phase_acc_q32 >>
                22U);

        int32_t sine =
            (int32_t)sine_lut[idx];

        uint16_t w =
            window_lut[win][n256];

        int32_t value =
            ((sine *
              (int32_t)swing) >>
             15);

        value =
            (value *
             (int32_t)w) >>
            15;

        if (mode == 3U) {

            uint32_t seg =
                (n256 * 13U) /
                256U;

            if (seg > 12U)
                seg = 12U;

            static const int8_t barker[13] =
                {1,1,1,1,1,-1,-1,
                 1,1,-1,1,-1,1};

            if (barker[seg] < 0)
                value = -value;
        }

        int32_t pwm =
            (int32_t)PWM_MID +
            value;

        if (pwm < 0)
            pwm = 0;

        if (pwm > (int32_t)PWM_MAX)
            pwm = PWM_MAX;

        buf[i] =
            (uint16_t)pwm;

        ++p;

        if (p >= total)
            p = 0U;
    }

    pulse_sample = p;
}

static void initialize_wave_buffer(void)
{
    phase_acc_q32 = 0U;
    pulse_sample = 0U;

    generate_wave_half(
        (uint16_t *)&wave_buf[0],
        WAVE_HALF);

    generate_wave_half(
        (uint16_t *)&wave_buf[WAVE_HALF],
        WAVE_HALF);
}

void HAL_TIM_PWM_PulseFinishedHalfCpltCallback(
    TIM_HandleTypeDef *htim)
{
    if (htim != NULL &&
        htim->Instance == TIM3) {

        apply_pending_config_if_ready();

        generate_wave_half(
            (uint16_t *)&wave_buf[0],
            WAVE_HALF);
    }
}

void HAL_TIM_PWM_PulseFinishedCallback(
    TIM_HandleTypeDef *htim)
{
    if (htim != NULL &&
        htim->Instance == TIM3) {

        apply_pending_config_if_ready();

        generate_wave_half(
            (uint16_t *)&wave_buf[WAVE_HALF],
            WAVE_HALF);
    }
}

static void read_self_monitor(void)
{
    mon_min = 4095U;
    mon_max = 0U;
    mon_sum = 0U;

    for (uint32_t i = 0U;
         i < TELEMETRY_ADC_SAMPLES;
         ++i) {

        ADC_ChannelConfTypeDef cfg = {0};

        cfg.Channel =
            ADC_CHANNEL_11; 

        cfg.Rank = 1;
        cfg.SamplingTime =
            ADC_SAMPLETIME_55CYCLES_5;

        if (HAL_ADC_ConfigChannel(
                &hadc2,
                &cfg) != HAL_OK) {

            mon_samples[i] = 0U;
            continue;
        }

        if (HAL_ADC_Start(
                &hadc2) != HAL_OK) {

            mon_samples[i] = 0U;
            continue;
        }

        if (HAL_ADC_PollForConversion(
                &hadc2,
                3U) != HAL_OK) {

            HAL_ADC_Stop(&hadc2);
            mon_samples[i] = 0U;
            continue;
        }

        uint16_t v =
            (uint16_t)HAL_ADC_GetValue(&hadc2);

        HAL_ADC_Stop(&hadc2);

        mon_samples[i] = v;

        if (v < mon_min)
            mon_min = v;

        if (v > mon_max)
            mon_max = v;

        mon_sum += v;
    }
}

static void send_dashboard(void)
{

    int len =
        snprintf(
            uart_buf,
            sizeof(uart_buf),

            "{"
            "\"depth\":%.1f,"
            "\"turbidity\":%.2f,"
            "\"temperature\":%.1f,"
            "\"res_pen\":%.2f,"
            "\"salinity\":%.1f,"
            "\"sound_speed\":%.1f,"
            "\"absorption\":%.2f,"
            "\"ph\":8.1,"
            "\"snr\":%.1f,"
            "\"center_freq\":%.1f,"
            "\"bandwidth\":%.1f,"
            "\"duration\":%.1f,"
            "\"amplitude\":%.2f,"
            "\"waveform_type\":%d,"
            "\"window_type\":%d,"
            "\"probe_active\":%d,"
            "\"probe_winner\":%d,"
            "\"probe_f1\":%.1f,"
            "\"probe_f2\":%.1f,"
            "\"probe_f3\":%.1f,"
            "\"probe_s1\":%.1f,"
            "\"probe_s2\":%.1f,"
            "\"probe_s3\":%.1f,"
            "\"adc_samples\":[",

            env.depth,
            env.turbidity,
            env.temperature,
            env.res_pen,
            env.salinity,
            env.sound_speed,
            env.absorption,
            env.snr,
            env.center_freq,
            env.bandwidth,
            env.duration,
            env.amplitude,
            env.mod_type,
            env.window_type,
            env.probe_active,
            env.probe_winner,
            env.probe_freqs[0],
            env.probe_freqs[1],
            env.probe_freqs[2],
            env.probe_snr[0],
            env.probe_snr[1],
            env.probe_snr[2]);

    if (len < 0)
        return;

    if ((size_t)len >= sizeof(uart_buf))
        return;

    for (uint32_t i = 0U;
         i < TELEMETRY_ADC_SAMPLES;
         ++i) {

        int remaining =
            (int)sizeof(uart_buf) -
            len -
            32;

        if (remaining <= 0)
            return;

        int wrote =
            snprintf(
                uart_buf + len,
                (size_t)remaining,
                "%u%s",
                (unsigned)mon_samples[i],
                (i == TELEMETRY_ADC_SAMPLES - 1U)
                    ? ""
                    : ",");

        if (wrote <= 0)
            return;

        if (wrote >= remaining)
            return;

        len += wrote;
    }

    int tail =
        snprintf(
            uart_buf + len,
            sizeof(uart_buf) - (size_t)len,
            "],"
            "\"adc2_min\":%u,"
            "\"adc2_max\":%u,"
            "\"adc2_mean\":%u"
            "}\n",
            (unsigned)mon_min,
            (unsigned)mon_max,
            (unsigned)(
                mon_sum /
                TELEMETRY_ADC_SAMPLES));

    if (tail <= 0)
        return;

    size_t total =
        (size_t)len +
        (size_t)tail;

    if (total >= sizeof(uart_buf))
        return;

    HAL_UART_Transmit(
        &huart2,
        (uint8_t *)uart_buf,
        (uint16_t)total,
        250U);
}
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
int main(void)
{
    HAL_Init();
    SystemClock_Config();

    MX_GPIO_Init();
    MX_DMA_Init();
    MX_ADC1_Init();
    MX_ADC2_Init();
    MX_USART2_UART_Init();
    MX_TIM3_Init();

    if (HAL_ADCEx_Calibration_Start(
            &hadc1) != HAL_OK) {

        Error_Handler();
    }

    if (HAL_ADCEx_Calibration_Start(
            &hadc2) != HAL_OK) {

        Error_Handler();
    }

    init_luts();

    read_pots();
    compute_environment();

    active_cfg =
        pending_cfg;

    config_pending = 0U;

    initialize_wave_buffer();

    if (HAL_TIM_PWM_Start_DMA(
            &htim3,
            TIM_CHANNEL_1,
            (uint32_t *)wave_buf,
            WAVE_BUF_SIZE) != HAL_OK) {

        Error_Handler();
    }

    uint32_t last_sensor_tick =
        HAL_GetTick();

    uint32_t last_telemetry_tick =
        HAL_GetTick();

    uint32_t led_tick =
        HAL_GetTick();

    while (1) {

        uint32_t now =
            HAL_GetTick();

        if ((uint32_t)(
                now -
                last_sensor_tick) >=
            SENSOR_PERIOD_MS) {

            last_sensor_tick =
                now;

            read_pots();
            compute_environment();
        }

        if ((uint32_t)(
                now -
                last_telemetry_tick) >=
            TELEMETRY_PERIOD_MS) {

            last_telemetry_tick =
                now;

            read_self_monitor();
            send_dashboard();
        }

        if ((uint32_t)(
                now -
                led_tick) >=
            500U) {

            led_tick =
                now;

            HAL_GPIO_TogglePin(
                GPIOC,
                GPIO_PIN_13);
        }
    }
}

void Error_Handler(void)
{
    __disable_irq();

    while (1) {
    }
}

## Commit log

2026-08-26 feat: complete AquaChirp Software-Defined Sonar Platform with STM32 hardware integration
2026-08-26 docs: update README with comprehensive AquaChirp architecture, acoustic physics, and STM32 pinout
2026-08-26 fix: map all STM32 snake_case firmware telemetry fields (depth, turbidity, center_freq, adc_samples)
2026-08-26 feat: support 256-sample ADC2 waveform frames from updated STM32 firmware
2026-08-26 fix: dynamic zero-mean normalization for 256 ADC samples and adaptive FFT frequency scale for hardware band
2026-08-26 fix: update all cursor ratios to N-1, set sampleCount and dacBufferLoad to 256, and calibrate dynamic FFT for hardware
2026-08-26 feat: remove pH and ambient noise sliders to match 5 physical STM32 potentiometers 1-to-1
2026-08-26 feat: complete all 8 telemetry fixes - accurate window envelopes, dynamic sample sizes, and STM32 F103RB TIM3 PWM register map
2026-08-26 fix: completely disable simulation timer in hardware mode and eliminate CPU status flickering
2026-08-26 feat: update waterfall spectrogram Y-axis to 0-12 kHz and label sample rate as Fs: 100 kSPS TIM3 PWM DMA
2026-09-05 Synchronize AquaChirp decision engine, bandwidth-resolution flow, firmware SNR telemetry, and UI temperature constraints
2026-09-17 fix: make LFM Chirp explicit rule visible in UI trace
2026-09-22 feat(sih26058): complete KESTREL adaptive sonar transmitter — firmware, hardware, mechanical CAD, web dashboard and documentation
    - Reorganize project into firmware/, hardware/, mechanical/cad/, docs/ pillars
    - Update firmware modulation rules to reference architecture (turbidity/depth thresholds)
    - Synchronize decisionEngine.ts with firmware modulation logic
    - Add professional README with architecture, pinout, signal chain and physics
    - Add Wiring Guide with complete pin-to-pin reference
    - Add Architecture.md with full system dataflow documentation
    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
    [AUV_hinge_pin.stl, AUV_payload_streamlined.stl, AUV_service_panel.stl]
2026-09-22 chore: clean up duplicate files and organize images into docs/images/
    [AUV_hinge_pin.stl, AUV_payload_streamlined.stl, AUV_service_panel.stl]
2026-09-22 docs: convert text flowcharts to Mermaid diagrams in README
2026-09-22 docs: update wiring guide with the 5-potentiometer prototype configuration

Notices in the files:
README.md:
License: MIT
